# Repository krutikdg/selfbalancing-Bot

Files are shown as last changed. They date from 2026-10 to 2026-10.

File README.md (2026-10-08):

# SelfbalanceBot
A two wheeled bot that stays upright by itself. It senses how far it is falling then decides how hard to push and drives it's wheels under itself to catch the fall.
<br>
This is my first robotics learning project. I built this to understand sensors function, PID control and motor drivers. 
<br>
## Built with 
- ESP32
- TB6612FNG
- TT gear Motors
- 2S18650 pack
- MPU9250
  <br>

final

# Bill Of Materials 
| Component | Quantity | Price/Unit (USD) | Purpose | Purchase Link |
|---|---|---|---|---|
| ESP32-WROOM-32 38-Pin Development Board | 1 | $4.18 | Main controller and PID processing | [Buy Here](https://robu.in/product/esp32-38pin-development-board-wifibluetooth-ultra-low-power-consumption-dual-core/) |
| MPU9250 9-Axis Module | 1 | $23.26 | Accelerometer and gyroscope for tilt sensing (magnetometer unused) | [Buy Here](https://robu.in/product/mpu9250-9-axis-attitude-gyro-accelerator-magnetometer-sensor-module-2/) |
| TB6612FNG Motor Driver | 1 | $1.54 | Dual H-bridge driver that switches battery current to the motors and sets their direction | [Buy Here](https://robu.in/product/motor-driver-tb6612fng-module-performance-ultra-small-volume-3-pi-matching-performance-ultra-l298n/) |
| 5V 200RPM TT DC Gear Motor 1:48 (Pair) | 1 | $4.65 | Geared motors that deliver the torque to correct the tilt | [Buy Here](https://robu.in/product/pair-5v-200rpm-microbit-tt-dc-motor-148/) |
| 65mm Robot Wheel for BO Motors | 2 | $0.28 | Drive wheels | [Buy Here](https://robu.in/product/robot-smart-car-wheel-tyre-bo-motor/) |
| 18650 Li-Ion Battery 3.7V 2000mAh | 1 | $0.64 | Rechargeable power source | [Buy Here](https://robocraze.com/products/3-7v-2000mah-18650-li-ion-battery?variant=41414818758809) |
| 18650 x 2 Battery Holder with Cover and On/Off Switch | 1 | $0.55 | Holds the cells safely and provides a power switch | [Buy Here](https://robu.in/product/18650-x-2-battery-holder-with-cover-and-on-off-switch/) |
| LM2596 DC-DC Buck Converter (Adjustable) | 1 | $0.45 | Steps battery voltage down to a stable 5V for the ESP32 | [Buy Here](https://robocraze.com/products/lm2596-dc-dc-buck-module?variant=40192693076121) |
| Male to Female Jumper Wires 40pcs 20cm | 1 | $0.46 | Prototyping connections between boards | [Buy Here](https://robu.in/product/male-to-female-jumper-wires-40pcs-20cm/) |
| Female to Female Dupont Wires 40pin 20cm | 1 | $1.63 | Prototyping connections between module headers | [Buy Here](https://robu.in/product/acebott-20cm-dupont-wire-40pin-female-to-female/) |
| 3-in-1 Soldering Iron Kit (25W iron + solder + flux) | 1 | $1.68 | Making permanent connections once the circuit is final | [Buy Here](https://www.amazon.in/dp/B07W32JT5N) |
| eSUN PLA Matte Deep Black 1.75mm Filament | 1 | $12.09 | 3D printing the chassis | [Buy Here](https://robu.in/product/esun-epla-gloss-1-75mm-3d-printing-filament-1kg/) |
| **Total** | | **$52.88** | | |

# Circuit Diagram
circuit diagram

**MPU9250 → ESP32**

| MPU9250 | ESP32 |
|---|---|
| VCC | 3.3V |
| GND | GND |
| SDA | GPIO TODO |
| SCL | GPIO TODO |

**TB6612FNG → ESP32**

| TB6612FNG | ESP32 |
|---|---|
| AIN1 / AIN2 | GPIO TODO / TODO |
| PWMA | GPIO TODO |
| BIN1 / BIN2 | GPIO TODO / TODO |
| PWMB | GPIO TODO |
| STBY | GPIO TODO |
| VCC (logic) | 3.3V |
| GND | GND |

**Motors:** left motor on A01/A02, right motor on B01/B02.

## Build steps

1. Print the chassis (f3d file in `/CAD`).
2. Test every module separately on a breadboard first: the IMU readings, then one motor at a time.
3. Wire everything following the tables above.
4. Assemble everything on the chassis.
5. Mount the MPU9250 **rigidly** and note its orientation. A wobbly sensor mount gives bad angle data.
6. Flash the firmware.
7. With the wheels off the ground, tilt the bot by hand. The wheels should spin in the direction of the tilt. If they spin the opposite way, flip the motor direction in the code.
8. Place it on a flat surface and tune.

## Tuning

Tune in this order and change one value at a time:

1. Set `Ki = 0` and `Kd = 0`.
2. Raise `Kp` until the bot reacts quickly and starts oscillating.
3. Add `Kd` until the oscillation calms down.
4. Add a small `Ki` only if the bot slowly leans to one side.
5. Adjust the target angle if the bot rests tilted because its weight is not centered.

PID values are specific to your weight, wheel size, motor and battery voltage. 

## Troubleshooting

| Symptom | Likely cause |
|---|---|
| Falls over instantly in one direction | Motor direction is reversed |
| Violent shaking | `Kp` too high, or `Kd` too low |
| Slow drift to one side | Tilt offset or imbalanced motors |
| Motors hum but do not move | PWM too low to overcome friction |
| Random resets | Power sag from motors; check buck converter and battery charge |
| Behaviour gets worse as the battery drains | Controller was tuned at a different voltage |

## CAD Models
Screenshot 2026-10-06 at 1 44 56 PM
WhatsApp Image 2026-10-07 at 12 15 59
Screenshot 2026-10-06 at 12 21 30 PM

## Testing Video

https://github.com/user-attachments/assets/a5a6a393-e260-479e-8745-cf48acce4c8e

https://github.com/user-attachments/assets/3d98c6a5-224b-486f-9dc2-2ef70e6621a0

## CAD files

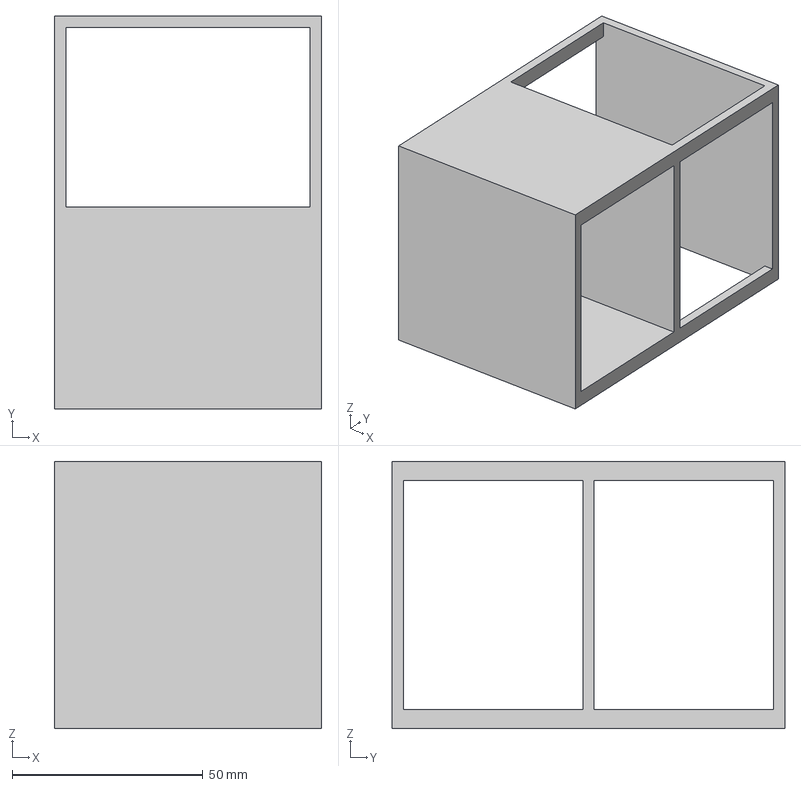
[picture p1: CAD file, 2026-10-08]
CAD/SelfBalBot.step
70.0 x 103.0 x 70.0 mm

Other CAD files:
CAD/SelfBalBot-f3d.f3d

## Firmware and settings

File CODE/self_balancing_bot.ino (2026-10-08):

#include <Wire.h>
#include <math.h>

#ifndef MODE
#define MODE 0
#endif

//pins
const int PIN_SDA = 21;
const int PIN_SCL = 22;
const int PWMA = 25, AIN1 = 26, AIN2 = 27;   // motor A
const int PWMB = 18, BIN1 = 32, BIN2 = 33;   // motor B
const int STBY = 4;

#ifndef FWD_AXIS
#define FWD_AXIS 0
#endif
const float IMU_SIGN = 1.0f;

//motors
const bool MOTOR_A_INV = false;   // flip direction of A
const bool MOTOR_B_INV = false;   // flip direction of B
const int MIN_PWM = 40;           // motor needs this much to move
const int MAX_PWM = 200;          // power cap
const int PWM_FREQ = 20000;       
const int PWM_BITS = 8;           

// control
const float ALPHA = 0.98f;                // filter, gyro vs accelerometer
const unsigned long LOOP_US = 5000;       
const float FALL_ANGLE = 35.0f;           
const float START_ANGLE = 3.0f;           
const unsigned long START_HOLD_MS = 500;  

float Kp = 12.0f, Ki = 0.0f, Kd = 0.6f;   // starting guesses
float trim = 0.0f;                        // angle (deg) where the bot actually balances

//IMU (raw I2C) 

const uint8_t MPU_ADDR = 0x68;   

struct Imu { float ax, ay, az, gx, gy, gz; };

bool mpuWrite(uint8_t reg, uint8_t val) {
  Wire.beginTransmission(MPU_ADDR);
  Wire.write(reg);
  Wire.write(val);
  return Wire.endTransmission() == 0;
}

bool mpuRead(uint8_t reg, uint8_t *buf, uint8_t len) {
  Wire.beginTransmission(MPU_ADDR);
  Wire.write(reg);
  if (Wire.endTransmission(false) != 0) return false;
  if (Wire.requestFrom((int)MPU_ADDR, (int)len) != len) return false;
  for (uint8_t i = 0; i < len; i++) buf[i] = Wire.read();
  return true;
}

bool initImu() {
  uint8_t who = 0;
  if (!mpuRead(0x75, &who, 1)) return false;
  Serial.printf("WHO_AM_I = 0x%02X\n", who);   // MPU6050 -> 0x68, MPU9250 -> 0x71 (verify in datasheet)
  mpuWrite(0x6B, 0x01);   // wake up, use gyro clock
  delay(100);
  mpuWrite(0x1A, 0x02);   // internal low-pass filter ~98 Hz
  mpuWrite(0x1B, 0x08);   // gyro  range +-500 deg/s  (65.5 LSB per deg/s)
  mpuWrite(0x1C, 0x00);   // accel range +-2 g        (16384 LSB per g)
  return true;
}

bool readImu(Imu &d) {
  uint8_t b[14];
  if (!mpuRead(0x3B, b, 14)) return false;
  int16_t ax = (int16_t)((b[0] << 8) | b[1]);
  int16_t ay = (int16_t)((b[2] << 8) | b[3]);
  int16_t az = (int16_t)((b[4] << 8) | b[5]);
  // b[6], b[7] = temperature (unused)
  int16_t gx = (int16_t)((b[8] << 8) | b[9]);
  int16_t gy = (int16_t)((b[10] << 8) | b[11]);
  int16_t gz = (int16_t)((b[12] << 8) | b[13]);
  d.ax = ax / 16384.0f;  d.ay = ay / 16384.0f;  d.az = az / 16384.0f;
  d.gx = gx / 65.5f;     d.gy = gy / 65.5f;     d.gz = gz / 65.5f;
  return true;
}

// Tilt from gravity. Forward lean = positive angle.
float accelAngle(const Imu &d) {
  float fwd = (FWD_AXIS == 0) ? d.ax : d.ay;
  return atan2f(-fwd, d.az) * 57.29578f * IMU_SIGN;
}

// Tipping speed (deg/s) about the wheel axle. Forward tip = positive.
float gyroRate(const Imu &d) {
  float r = (FWD_AXIS == 0) ? d.gy : -d.gx;
  return r * IMU_SIGN;
}

// MOTORS 

void pwmSetup() {
#if defined(ESP_ARDUINO_VERSION_MAJOR) && ESP_ARDUINO_VERSION_MAJOR >= 3
  ledcAttach(PWMA, PWM_FREQ, PWM_BITS);
  ledcAttach(PWMB, PWM_FREQ, PWM_BITS);
#else
  ledcSetup(0, PWM_FREQ, PWM_BITS);  ledcAttachPin(PWMA, 0);
  ledcSetup(1, PWM_FREQ, PWM_BITS);  ledcAttachPin(PWMB, 1);
#endif
}

void pwmWrite(int motor, int duty) {
#if defined(ESP_ARDUINO_VERSION_MAJOR) && ESP_ARDUINO_VERSION_MAJOR >= 3
  ledcWrite(motor == 0 ? PWMA : PWMB, duty);
#else
  ledcWrite(motor, duty);
#endif
}

// motor: 0 = A, 1 = B.  speed: -255..255, positive = bot rolls FORWARD.
void driveMotor(int motor, int speed) {
  bool inv = (motor == 0) ? MOTOR_A_INV : MOTOR_B_INV;
  if (inv) speed = -speed;
  int in1 = (motor == 0) ? AIN1 : BIN1;
  int in2 = (motor == 0) ? AIN2 : BIN2;
  digitalWrite(in1, speed > 0 ? HIGH : LOW);
  digitalWrite(in2, speed < 0 ? HIGH : LOW);
  pwmWrite(motor, abs(speed));
}

void motorsOn()  { digitalWrite(STBY, HIGH); }

void motorsOff() {
  driveMotor(0, 0);
  driveMotor(1, 0);
  digitalWrite(STBY, LOW);
}

// STATE

float angle = 0.0f;      // filtered tilt (deg)
float rate = 0.0f;       // tipping speed (deg/s)
float gyroBias = 0.0f;
float integ = 0.0f;
bool active = false;
unsigned long upSince = 0;
unsigned long lastUs = 0;
unsigned long lastPrint = 0;

//SERIAL TUNING

void parseCommand(char *s) {
  float v = atof(s + 1);
  switch (s[0]) {
    case 'p': Kp = v; break;
    case 'i': Ki = v; integ = 0; break;
    case 'd': Kd = v; break;
    case 't': trim = v; break;
    default: break;
  }
  Serial.printf("Kp=%.2f Ki=%.3f Kd=%.3f trim=%.2f\n", Kp, Ki, Kd, trim);
}

void handleSerial() {
  static char buf[24];
  static uint8_t n = 0;
  while (Serial.available()) {
    char c = (char)Serial.read();
    if (c == '\n' || c == '\r') {
      if (n > 0) { buf[n] = 0; parseCommand(buf); n = 0; }
    } else if (n < sizeof(buf) - 1) {
      buf[n++] = c;
    }
  }
}

//SETUP

void calibrateGyro() {
  Serial.println("Calibrating gyro - keep the bot STILL...");
  float sum = 0.0f;
  int n = 0;
  for (int i = 0; i < 500; i++) {
    Imu d;
    if (readImu(d)) { sum += gyroRate(d); n++; }
    delay(3);
  }
  gyroBias = (n > 0) ? sum / n : 0.0f;
  Serial.printf("Gyro bias = %.3f deg/s\n", gyroBias);
}

void setup() {
  Serial.begin(115200);
  delay(300);

  pinMode(AIN1, OUTPUT); pinMode(AIN2, OUTPUT);
  pinMode(BIN1, OUTPUT); pinMode(BIN2, OUTPUT);
  pinMode(STBY, OUTPUT);
  pwmSetup();
  motorsOff();

  Wire.begin(PIN_SDA, PIN_SCL);
  Wire.setClock(400000);

  if (!initImu()) {
    Serial.println("IMU not found. Check SDA/SCL/3V3/GND and AD0 -> GND.");
    while (true) delay(1000);   // stop here, motors stay off
  }

  calibrateGyro();

  Imu d;
  if (readImu(d)) angle = accelAngle(d);   // start the filter from the accelerometer

  upSince = millis();
  lastUs = micros();
  Serial.printf("Ready. MODE = %d\n", MODE);
}

//MOTOR TEST (MODE 1)

void motorTest() {
  motorsOn();
  Serial.println("Motor A forward");  driveMotor(0, 120); driveMotor(1, 0);   delay(1500);
  Serial.println("Motor A backward"); driveMotor(0, -120); driveMotor(1, 0);  delay(1500);
  Serial.println("Motor B forward");  driveMotor(0, 0); driveMotor(1, 120);   delay(1500);
  Serial.println("Motor B backward"); driveMotor(0, 0); driveMotor(1, -120);  delay(1500);
  Serial.println("Both forward (both wheels should roll the bot FORWARD)");
  driveMotor(0, 120); driveMotor(1, 120);                                     delay(2000);
  motorsOff();
  Serial.println("Stopped. Pausing...");
  delay(3000);
}

//BALANCE (MODE 2)

void balanceStep(float dt) {
  float err = angle - trim;

  if (!active) {
    // wait until the bot is held upright and still
    if (fabsf(err) < START_ANGLE) {
      if (millis() - upSince > START_HOLD_MS) {
        active = true;
        integ = 0.0f;
        motorsOn();
      }
    } else {
      upSince = millis();
    }
    return;
  }

  if (fabsf(angle) > FALL_ANGLE) {   // fell over
    active = false;
    motorsOff();
    upSince = millis();
    return;
  }

  integ += err * dt;
  integ = constrain(integ, -50.0f, 50.0f);

  float u = Kp * err + Ki * integ + Kd * rate;

  int pwm = 0;
  float a = fabsf(u);
  if (a > 1.0f) pwm = (int)fminf(a + MIN_PWM, (float)MAX_PWM);
  int speed = (u > 0) ? pwm : -pwm;

  driveMotor(0, speed);
  driveMotor(1, speed);
}

//MAIN LOOP

void loop() {
#if MODE == 1
  motorTest();
  return;
#endif

  handleSerial();

  unsigned long now = micros();
  if (now - lastUs < LOOP_US) return;
  float dt = (now - lastUs) * 1e-6f;
  lastUs = now;

  Imu d;
  if (!readImu(d)) {
    motorsOff();
    active = false;
    return;
  }

  // ---- 1. SENSE: one clean angle ----
  rate = gyroRate(d) - gyroBias;
  float accAng = accelAngle(d);
  angle = ALPHA * (angle + rate * dt) + (1.0f - ALPHA) * accAng;

  // ---- 2. THINK + 3. ACT ----
#if MODE == 2
  balanceStep(dt);
#endif

  // ---- print at 10 Hz (printing every loop would slow the 200 Hz timing) ----
  if (millis() - lastPrint >= 100) {
    lastPrint = millis();
    Serial.printf("angle:%.1f rate:%.1f active:%d\n", angle, rate, active ? 1 : 0);
  }
}

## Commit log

2026-10-08 added bill of materials
    [BOM.csv]
2026-10-08 added cad model
    [SelfBalBot-f3d.f3d, SelfBalBot.step]
